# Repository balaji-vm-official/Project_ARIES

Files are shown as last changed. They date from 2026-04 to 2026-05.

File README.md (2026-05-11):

# Project ARIES: Automatic Robotic Interchangeable End Effector System

  **Project ARIES** is a smart, universal connector system designed to transform single-purpose robotic arms into versatile, multi-purpose industrial tools. By automating the end-effector switching process, ARIES eliminates manual intervention and reduces operational downtime.

  The system features a unique **Passive Docking Mechanism**: it requires no electricity to dock/undock, yet includes a dedicated power passthrough section to provide electricity to the end-effectors once connected.

---

## 🛠 System Overview

The system consists of three primary layers:

1. **Host:** The robotic arm.
2. **Connector:** The bridge between the host and tool, featuring three distinct sections:
    * **Top:** A specialized cut section for host engagement.
    * **Body:** Dual spring-activated mechanisms for secure locking and load-bearing.
    * **Bottom:** The interface where the specific end-effector is mounted.

3. **End-Effectors:** Currently supports a Mechanical Gripper and a Magnetic Gripper.

### Control Stack

The robotic arm is controlled via **ROS2 Jazzy** and **MoveIt2** for path planning, with hardware execution handled by an **Arduino UNO R3**.

> [!NOTE]
> For deep-dive technical details, please view the explanation files in each directory:
> [3D CAD Models](https://github.com/balaji-vm-official/Project_ARIES/blob/main/3D_CAD_Models/3D_CAD_Models.Explanation.md) | [Circuit Diagram](https://github.com/balaji-vm-official/Project_ARIES/blob/main/Circuit_Diagram/Circuit_Diagram.Explanation.md) | [ROS Workspace](https://github.com/balaji-vm-official/Project_ARIES/blob/main/ros-ws/ros-ws.Explanation.md)

---

## 📄 Publication & Citation

This project has been peer-reviewed and published in the *EPJ Web of Conferences*.

* **Title:** Automatic Robotic Interchangeable End Effector System (ARIES)
* **Authors:** Balaji V. M., Ponnarasan S. A., Srinivasan K., K. K. Manivannan, K. Gobivel
* **Journal:** *EPJ Web of Conferences*, Vol. 363, 01005 (2026)
* **Link:** [Read the full paper here](https://www.epj-conferences.org/10.1051/epjconf/202636301005)

### Citation (BibTeX)

If you use this work or codebase in your research, please use the following citation:

```bibtex
@article{aries2026,
  author = {Balaji, V. M. and Ponnarasan, S. A. and Srinivasan, K. and Manivannan, K. K. and Gobivel, K.},
  title = {Automatic Robotic Interchangeable End Effector System (ARIES)},
  journal = {EPJ Web of Conferences},
  volume = {363},
  pages = {01005},
  year = {2026},
  doi = {10.1051/epjconf/202636301005}
}

```

---

## 📸 Media Gallery

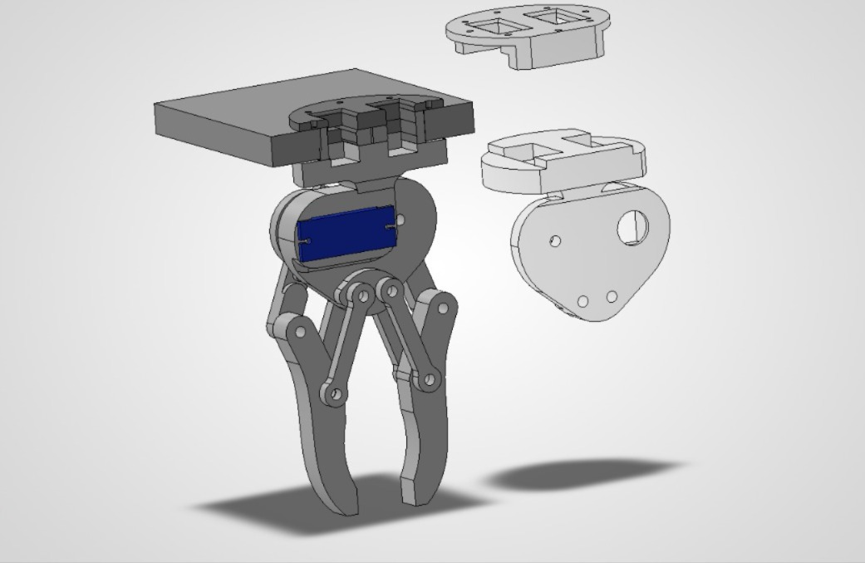
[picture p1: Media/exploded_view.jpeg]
Exploded view


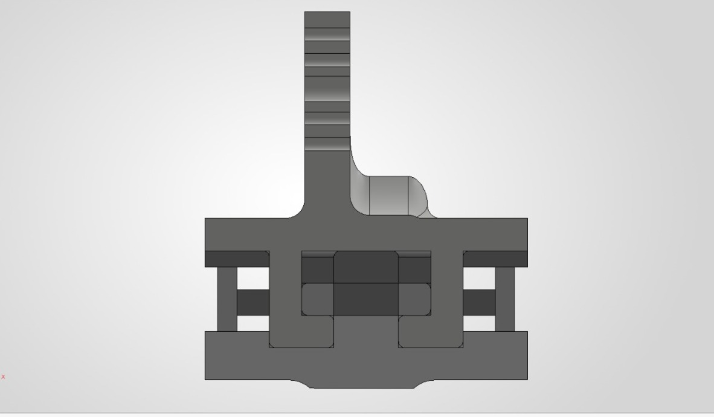
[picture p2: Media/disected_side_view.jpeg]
Disected view


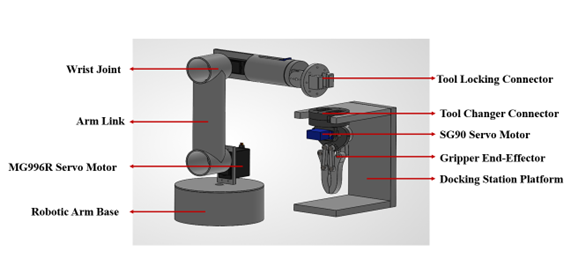
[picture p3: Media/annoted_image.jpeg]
Annoted image


---

## 🚀 Setup & Installation

### Software Requirements

* **ROS2 Jazzy:** [Installation Guide](https://docs.ros.org/en/jazzy/Installation/Ubuntu-Install-Debs.html)
* **MoveIt2:** [Binary Installation](https://moveit.ai/install-moveit2/binary/)
* **Arduino IDE:** [Download](https://www.arduino.cc/en/software/)
* **KiCAD:** [PCB Design Suite](https://www.kicad.org/download/)
* **SW to URDF Exporter:** [Wiki Link](https://wiki.ros.org/sw_urdf_exporter)

### Documentation & Resources

* **Official ROS Documentation:** [ROS Wiki](https://wiki.ros.org/)
* **MoveIt2 Tutorials:** [Setup Assistant Guide](https://moveit.picknik.ai/main/doc/examples/setup_assistant/setup_assistant_tutorial.html)
* **CAD Models:** [GrabCAD Library](https://grabcad.com/library)

---

## 👥 Contributors

* **Balaji V. M.** ([@balaji-vm-official](https://www.google.com/search?q=https://github.com/balaji-vm-official))
* **Ponnarasan S. A.**
* **Srinivasan K.**
* **Supervisor:** Mr. K.K. Manivannan (Assistant Professor, Mechatronics Engineering)

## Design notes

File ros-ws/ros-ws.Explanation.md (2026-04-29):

First install ROS2 and MoveIt2 from the given link before starting.<br/>  <br/> 

To avoid sourcing ros2 and it's required components everytime in the terminal individually and also not wanting to to also upload in the "~/.bashrc" file. 
I used the "ros2.sh" file to source everytime when it needed.

But before using the "ros2.sh" file make sure to change the location of the ros-ws folder as per the location that you saved. 
This file is movable so, if you move this file to home you can source it directly without any hassle. 

The robotic arm's model is given as "roboassem.urdf" and the gripper's models (that also includes both connector and the end effector) is given as "holdassem.urdf".

To simulate both model at same time, i used full.xacro to combine both the robotic arm (roboassem.urdf.xacro) and gripper (holdassem.urdf.xacro).
So to run each urdf file, i made seperate launch.py file to simulate in Rviz2. One launch.py file and one controller.yaml for each urdf.xacro file.<br/>  <br/> 

To make the already existing file compatable with MoveIt2, put the following command in terminal after sourcing to get a setup file make this process simple.
    
    "ros2 launch moveit_setup_assistant setup_assistant.launch.py" 

To launch the Moveit2 file run the following command in terminal after sourcing.
    
    "ros2 launch panda_moveit_config demo.launch.py" 

To connect MoveIt2 and Arduino UNO R3, <br/>  <br/> 

- First upload "ard_connect.ino" in the ard-connect folder (ros-ws/src/aries/ard_connect).
- Next run "ros2_to_arduino_bridge.py" in seperate terminal after the demo.launch.py is launched.
- Finally run "run_sequence.py" in seperate terminal if you want to want to run the robotic arm in pre planned sequence. This also work even when Arduino is not connected.<br/>  <br/> 

To learn more, visit the official documentations to get clear in-depth knowledge.

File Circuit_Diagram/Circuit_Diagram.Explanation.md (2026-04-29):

This circuit is made using KiCAD a free open source software. This is a accurate depiction of the circuit connected to the robotic arm for ROS2 control. 

Each servo motor is connected directly to a PWM suppported pin the Arduino UNO R3 that is given by,

   - 03 - rotate1 
   - 05 - link1
   - 06 - link2
   - 09 - rotate2
   - 10 - end
   - 11 - gripper

The Arduino UNO and all servo motors are directly powered by a 5V adapter so that the motors can gets uninterrupted power supply.

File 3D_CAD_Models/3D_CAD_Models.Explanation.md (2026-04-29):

This project is totally made in SolidWorks and some generic parts like motors are taken from GrabCAD. 

- holdassem folder consist of all the parts related to the connector.

- roboassem folder consist of all the parts related to the robotic arm.

- SolidWorks to URDF folder consist of urdf files that are directly converted from the assembly file using "SolidWorks to URDF Exporter" tool. 

- This URDF can work on both ROS1 and ROS2 but the launch files directly works on ROS1 and not on ROS2. ROS2 needs its own launch.py file to show in Rviz2.

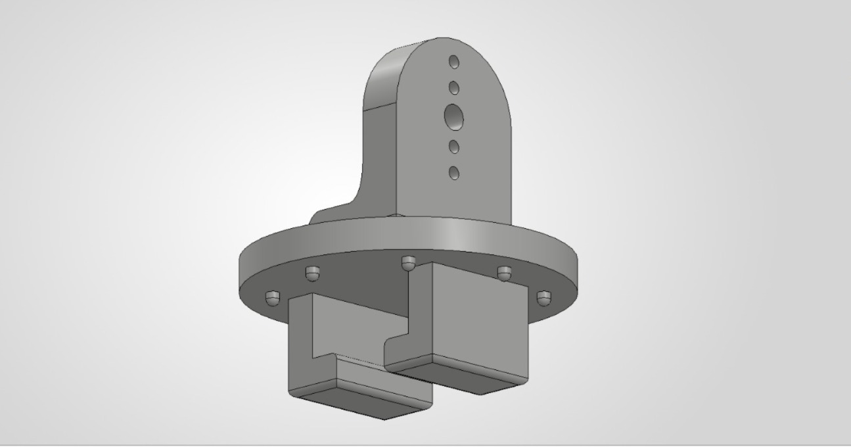
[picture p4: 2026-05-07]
Media/arm_end.jpeg

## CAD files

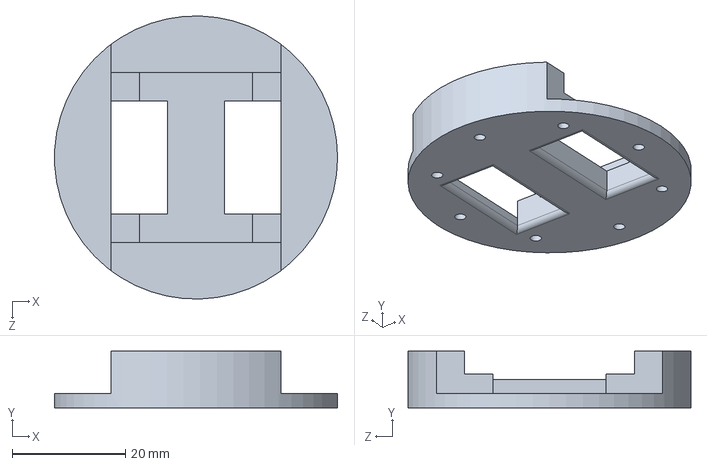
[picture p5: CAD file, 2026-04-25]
3D_CAD_Models/holdassem/connector/top.SLDPRT
50.0 x 10.0 x 50.0 mm

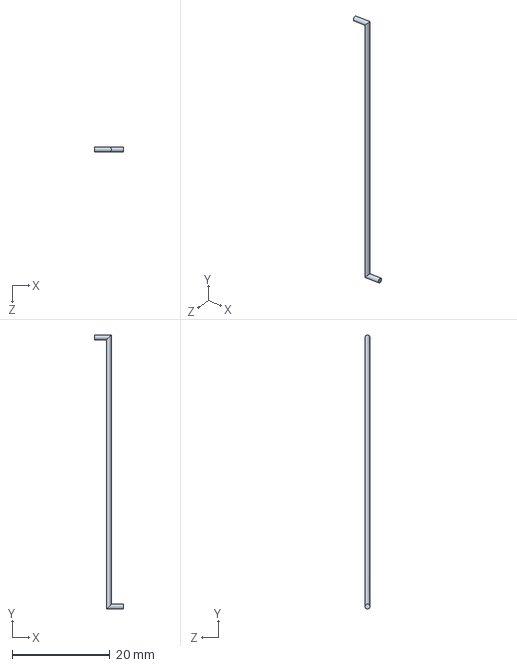
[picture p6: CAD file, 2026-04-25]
3D_CAD_Models/holdassem/mag_gripper/mlink.SLDPRT
6.00 x 56.0 x 1.00 mm

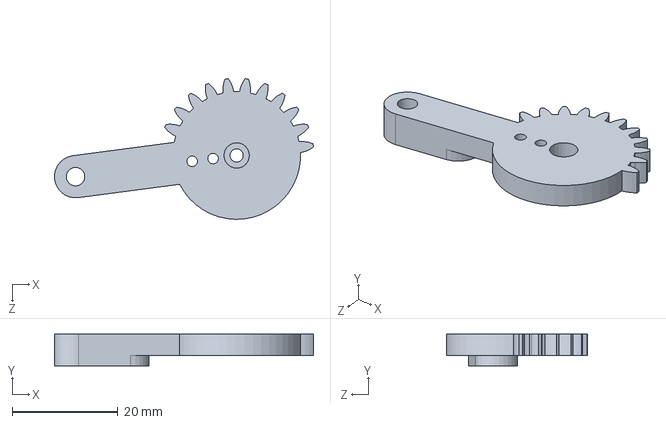
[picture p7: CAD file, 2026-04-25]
3D_CAD_Models/holdassem/mech_gripper/sgear.SLDPRT
49.0 x 6.00 x 26.6 mm

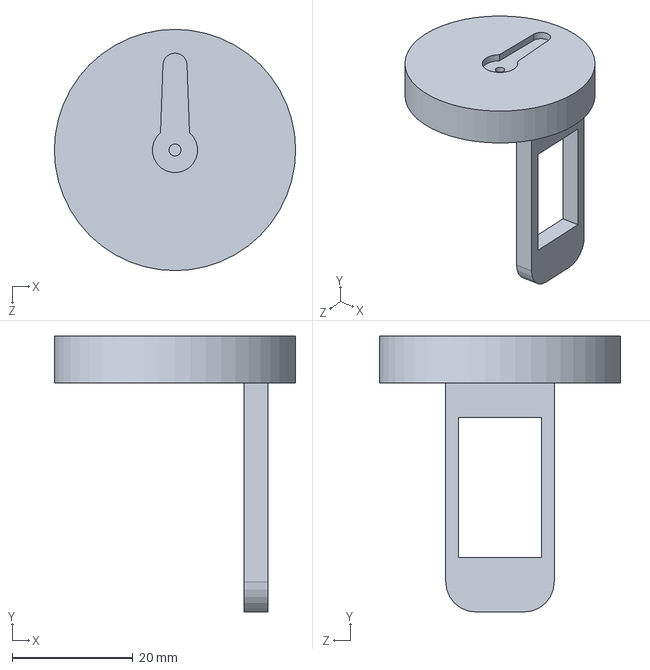
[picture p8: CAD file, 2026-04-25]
3D_CAD_Models/roboassem/rotate2.SLDPRT
40.0 x 45.8 x 40.0 mm

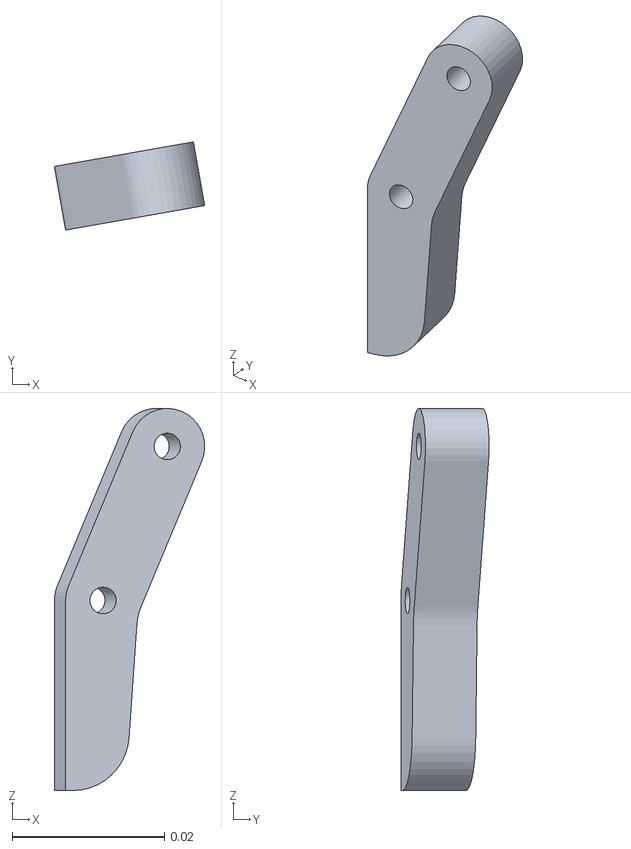
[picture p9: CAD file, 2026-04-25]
3D_CAD_Models/SolidWorks to URDF/holdassem/meshes/sfinger.STL
0.0198 x 0.0116 x 0.0503

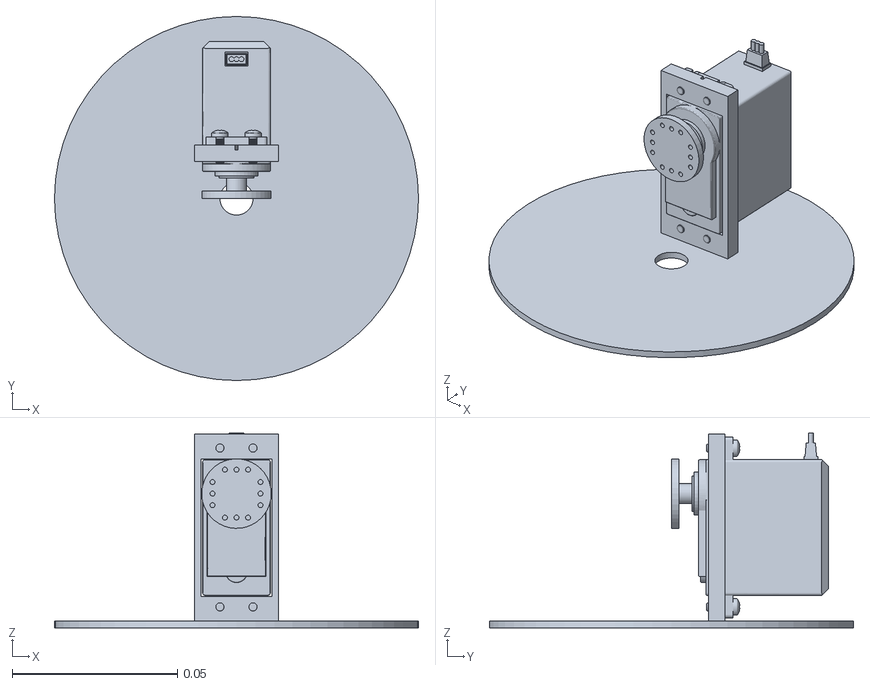
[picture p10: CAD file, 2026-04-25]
3D_CAD_Models/SolidWorks to URDF/roboassem/meshes/rotate1.STL
0.11 x 0.11 x 0.0588

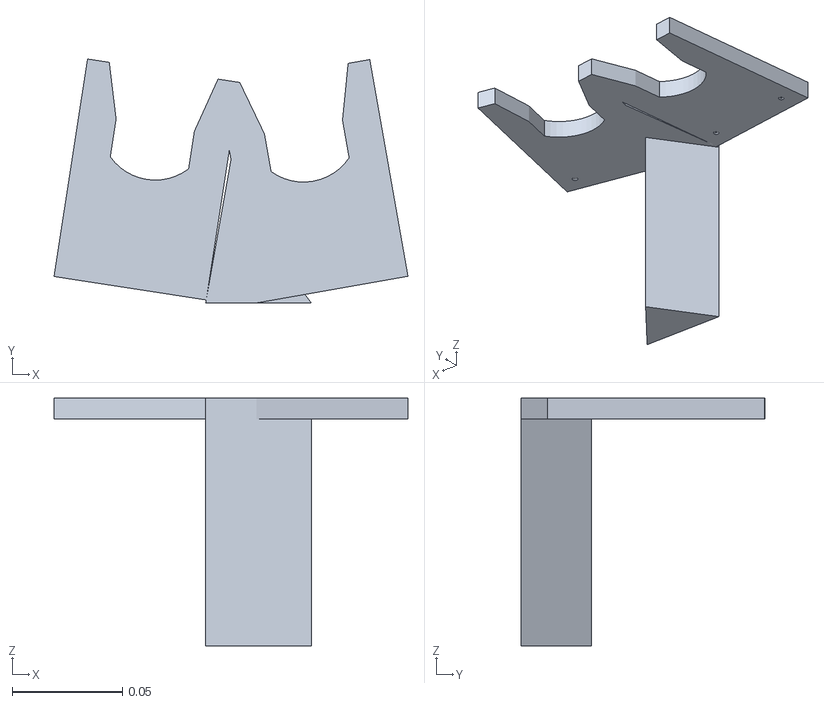
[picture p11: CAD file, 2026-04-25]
ros-ws/src/aries/meshes/holdassem/hbase.STL
0.161 x 0.111 x 0.112

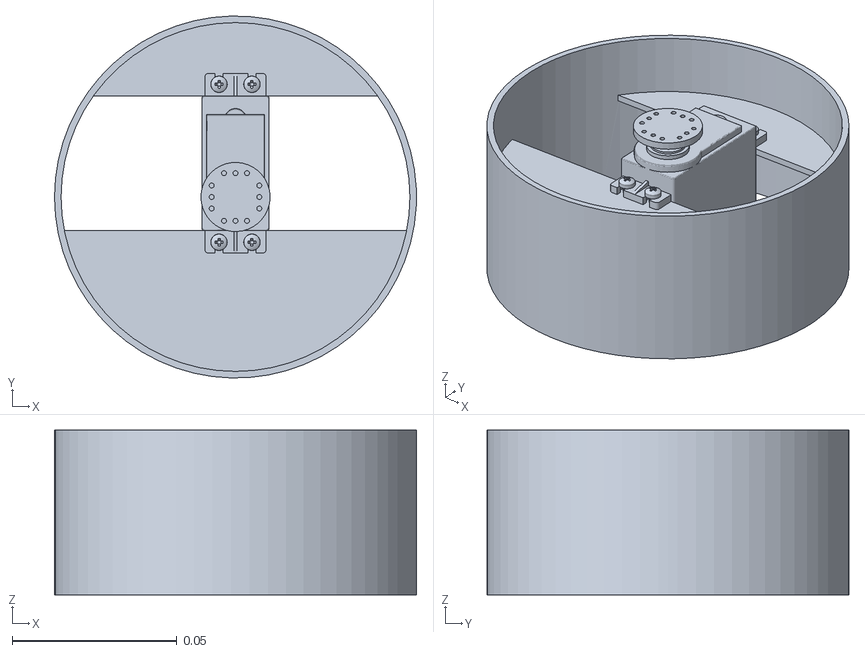
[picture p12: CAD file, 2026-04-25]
ros-ws/src/aries/meshes/roboassem/base.STL
0.11 x 0.11 x 0.05

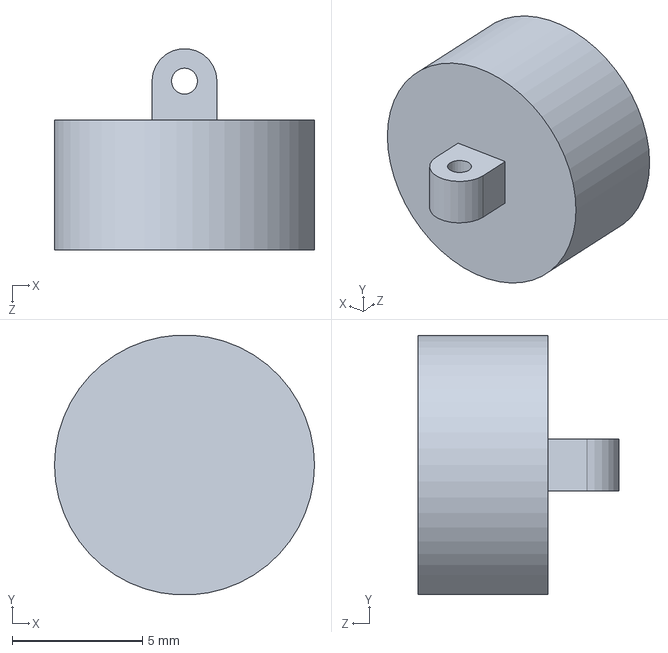
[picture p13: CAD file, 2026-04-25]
3D_CAD_Models/holdassem/mag_gripper/magnet.SLDPRT
10.0 x 9.98 x 7.74 mm

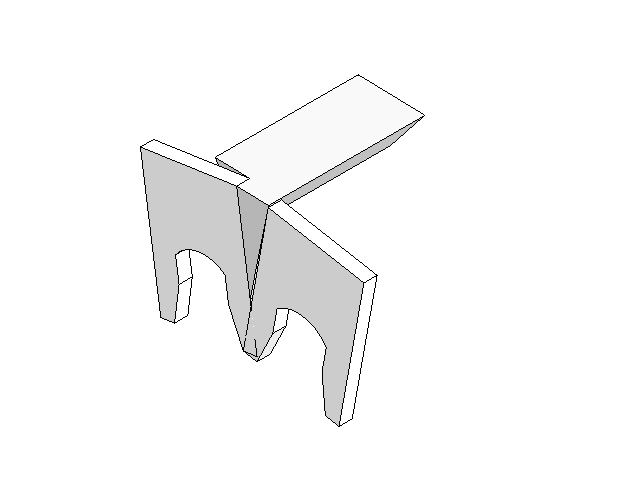
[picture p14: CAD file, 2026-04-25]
3D_CAD_Models/holdassem/hbase.SLDASM
stand
holder x 2

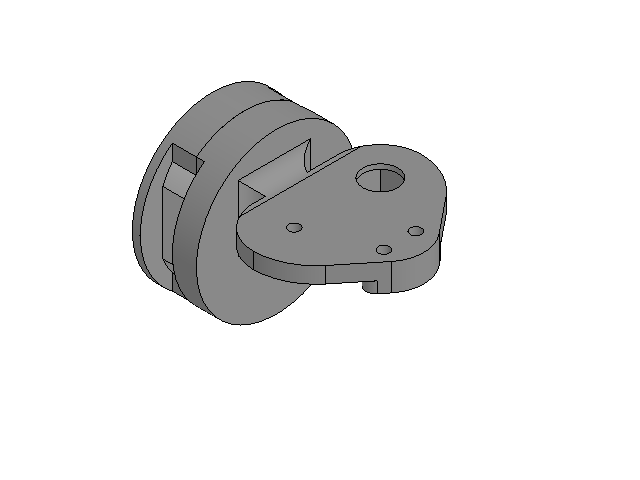
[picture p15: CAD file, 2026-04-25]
3D_CAD_Models/holdassem/connector/connector assem.SLDASM
bottom
button x 2
top

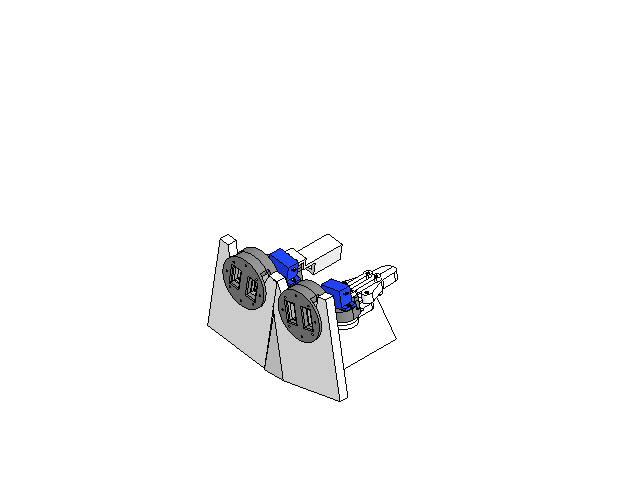
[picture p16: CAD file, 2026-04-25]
3D_CAD_Models/holdassem/holdassem.SLDASM
stand
holder x 2
bottom x 2
button x 4
top x 2
Servo Micro x 2
Microservo horn x 2
mag holder
magnet
mlink
cr pan head screw_is x 16
sgear
gear
link x 4
finger x 2

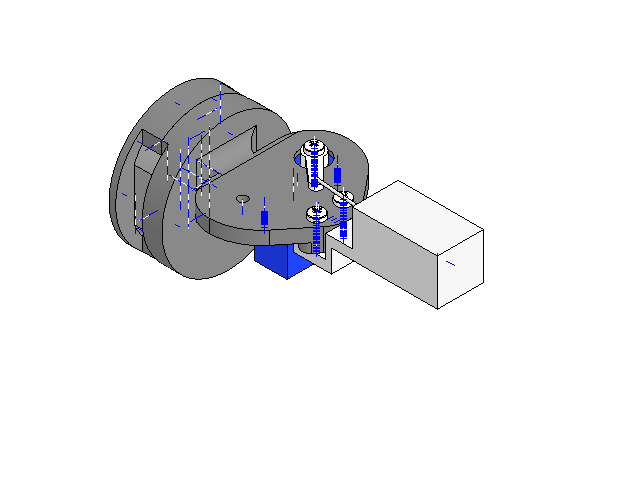
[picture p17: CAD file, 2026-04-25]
3D_CAD_Models/holdassem/mag_gripper/mag gripper assem.SLDASM
bottom
button x 2
top
Servo Micro
Microservo horn
mag holder
magnet
mlink
cr pan head screw_is x 5

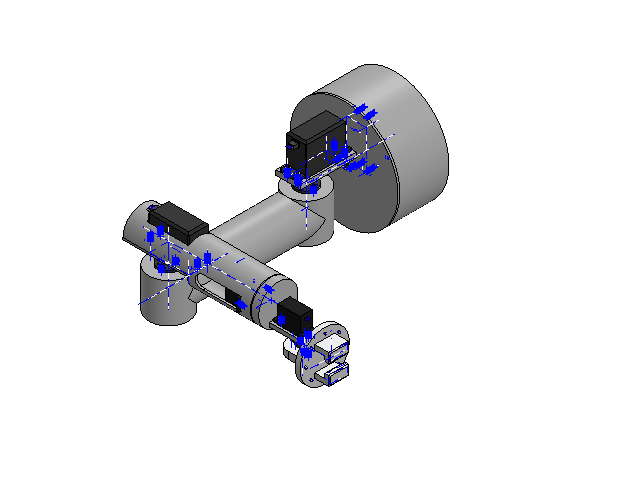
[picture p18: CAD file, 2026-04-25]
3D_CAD_Models/roboassem/roboassem.SLDASM
rotate1
base
motorb x 3
link1
link2
motors x 2
rotate2
motors_horn x 2
Component1.step
cr pan head screw_is x 25

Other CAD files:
3D_CAD_Models/holdassem/mech_gripper/mech gripper Assem trial.SLDASM
3D_CAD_Models/holdassem/mech_gripper/mech gripper Assem.SLDASM
ros-ws/install/aries/share/aries/meshes/holdassem/finger.STL
ros-ws/install/aries/share/aries/meshes/roboassem/link1.STL
3D_CAD_Models/SolidWorks to URDF/holdassem/meshes/button1.STL
3D_CAD_Models/SolidWorks to URDF/holdassem/meshes/button2.STL
3D_CAD_Models/SolidWorks to URDF/holdassem/meshes/connector.STL
3D_CAD_Models/SolidWorks to URDF/holdassem/meshes/finger.STL
3D_CAD_Models/SolidWorks to URDF/holdassem/meshes/gear.STL
3D_CAD_Models/SolidWorks to URDF/holdassem/meshes/horn.STL
3D_CAD_Models/SolidWorks to URDF/holdassem/meshes/link.STL
3D_CAD_Models/SolidWorks to URDF/holdassem/meshes/magnet.STL
3D_CAD_Models/SolidWorks to URDF/holdassem/meshes/mbutton1.STL
3D_CAD_Models/SolidWorks to URDF/holdassem/meshes/mbutton2.STL
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

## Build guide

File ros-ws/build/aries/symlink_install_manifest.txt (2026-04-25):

/home/comrade/Documents/Project_ARIES/ros-ws/install/aries/share/aries/ard_connect/ard_connect.ino
/home/comrade/Documents/Project_ARIES/ros-ws/install/aries/share/aries/ard_connect/ros2_to_arduino_bridge.py
/home/comrade/Documents/Project_ARIES/ros-ws/install/aries/share/aries/ard_connect/run_sequence.py
/home/comrade/Documents/Project_ARIES/ros-ws/install/aries/share/aries/config/ardcontroller.yaml
/home/comrade/Documents/Project_ARIES/ros-ws/install/aries/share/aries/config/fullcontroller.yaml
/home/comrade/Documents/Project_ARIES/ros-ws/install/aries/share/aries/config/holdcontroller.yaml
/home/comrade/Documents/Project_ARIES/ros-ws/install/aries/share/aries/config/robocontroller.yaml
/home/comrade/Documents/Project_ARIES/ros-ws/install/aries/share/aries/launch/full_rviz.launch.py
/home/comrade/Documents/Project_ARIES/ros-ws/install/aries/share/aries/launch/holdassem_rviz.launch.py
/home/comrade/Documents/Project_ARIES/ros-ws/install/aries/share/aries/launch/roboassem_rviz.launch.py
/home/comrade/Documents/Project_ARIES/ros-ws/install/aries/share/aries/meshes/holdassem/button1.STL
/home/comrade/Documents/Project_ARIES/ros-ws/install/aries/share/aries/meshes/holdassem/button2.STL
/home/comrade/Documents/Project_ARIES/ros-ws/install/aries/share/aries/meshes/holdassem/connector.STL
/home/comrade/Documents/Project_ARIES/ros-ws/install/aries/share/aries/meshes/holdassem/finger.STL
/home/comrade/Documents/Project_ARIES/ros-ws/install/aries/share/aries/meshes/holdassem/gear.STL
/home/comrade/Documents/Project_ARIES/ros-ws/install/aries/share/aries/meshes/holdassem/hbase.STL
/home/comrade/Documents/Project_ARIES/ros-ws/install/aries/share/aries/meshes/holdassem/horn.STL
/home/comrade/Documents/Project_ARIES/ros-ws/install/aries/share/aries/meshes/holdassem/link.STL
/home/comrade/Documents/Project_ARIES/ros-ws/install/aries/share/aries/meshes/holdassem/magnet.STL
/home/comrade/Documents/Project_ARIES/ros-ws/install/aries/share/aries/meshes/holdassem/mbutton1.STL
/home/comrade/Documents/Project_ARIES/ros-ws/install/aries/share/aries/meshes/holdassem/mbutton2.STL
/home/comrade/Documents/Project_ARIES/ros-ws/install/aries/share/aries/meshes/holdassem/mconnector.STL
/home/comrade/Documents/Project_ARIES/ros-ws/install/aries/share/aries/meshes/holdassem/rod.STL
/home/comrade/Documents/Project_ARIES/ros-ws/install/aries/share/aries/meshes/holdassem/sfinger.STL
/home/comrade/Documents/Project_ARIES/ros-ws/install/aries/share/aries/meshes/holdassem/sgear.STL
/home/comrade/Documents/Project_ARIES/ros-ws/install/aries/share/aries/meshes/holdassem/slink.STL
/home/comrade/Documents/Project_ARIES/ros-ws/install/aries/share/aries/meshes/roboassem/base.STL
/home/comrade/Documents/Project_ARIES/ros-ws/install/aries/share/aries/meshes/roboassem/end.STL
/home/comrade/Documents/Project_ARIES/ros-ws/install/aries/share/aries/meshes/roboassem/link1.STL
/home/comrade/Documents/Project_ARIES/ros-ws/install/aries/share/aries/meshes/roboassem/link2.STL
/home/comrade/Documents/Project_ARIES/ros-ws/install/aries/share/aries/meshes/roboassem/rotate1.STL
/home/comrade/Documents/Project_ARIES/ros-ws/install/aries/share/aries/meshes/roboassem/rotate2.STL
/home/comrade/Documents/Project_ARIES/ros-ws/install/aries/share/aries/urdf/full.xacro
/home/comrade/Documents/Project_ARIES/ros-ws/install/aries/share/aries/urdf/holdassem.csv
/home/comrade/Documents/Project_ARIES/ros-ws/install/aries/share/aries/urdf/holdassem.urdf
/home/comrade/Documents/Project_ARIES/ros-ws/install/aries/share/aries/urdf/roboassem.csv
/home/comrade/Documents/Project_ARIES/ros-ws/install/aries/share/aries/urdf/roboassem.urdf
/home/comrade/Documents/Project_ARIES/ros-ws/install/aries/share/aries/worlds/holdassem.rviz
/home/comrade/Documents/Project_ARIES/ros-ws/install/aries/share/aries/worlds/roboassem.rviz
/home/comrade/Documents/Project_ARIES/ros-ws/install/aries/lib/aries/ros2_to_arduino_bridge.py
/home/comrade/Documents/Project_ARIES/ros-ws/install/aries/share/ament_index/resource_index/package_run_dependencies/aries
/home/comrade/Documents/Project_ARIES/ros-ws/install/aries/share/ament_index/resource_index/parent_prefix_path/aries
/home/comrade/Documents/Project_ARIES/ros-ws/install/aries/share/aries/environment/ament_prefix_path.sh
/home/comrade/Documents/Project_ARIES/ros-ws/install/aries/share/aries/environment/ament_prefix_path.dsv
/home/comrade/Documents/Project_ARIES/ros-ws/install/aries/share/aries/environment/path.sh
/home/comrade/Documents/Project_ARIES/ros-ws/install/aries/share/aries/environment/path.dsv
/home/comrade/Documents/Project_ARIES/ros-ws/install/aries/share/aries/local_setup.bash
/home/comrade/Documents/Project_ARIES/ros-ws/install/aries/share/aries/local_setup.sh
/home/comrade/Documents/Project_ARIES/ros-ws/install/aries/share/aries/local_setup.zsh
/home/comrade/Documents/Project_ARIES/ros-ws/install/aries/share/aries/local_setup.dsv
/home/comrade/Documents/Project_ARIES/ros-ws/install/aries/share/aries/package.dsv
/home/comrade/Documents/Project_ARIES/ros-ws/install/aries/share/ament_index/resource_index/packages/aries
/home/comrade/Documents/Project_ARIES/ros-ws/install/aries/share/aries/cmake/ariesConfig.cmake
/home/comrade/Documents/Project_ARIES/ros-ws/install/aries/share/aries/cmake/ariesConfig-version.cmake
/home/comrade/Documents/Project_ARIES/ros-ws/install/aries/share/aries/package.xml

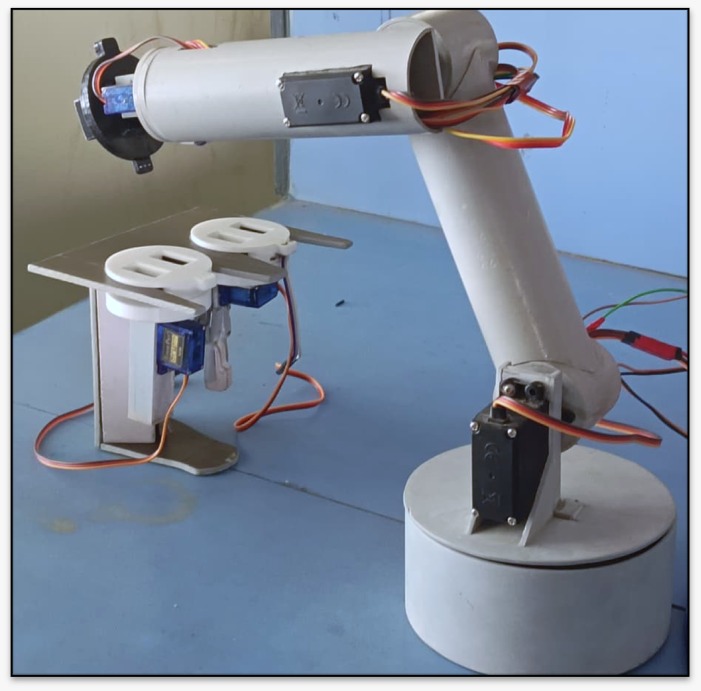
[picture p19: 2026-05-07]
Media/full_setup.jpeg

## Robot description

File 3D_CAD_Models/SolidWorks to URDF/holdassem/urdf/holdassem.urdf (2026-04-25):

<?xml version="1.0" encoding="utf-8"?>
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
<robot name="holdassem">
  <link name="hbase">
    <inertial>
      <origin xyz="-0.0080385 0.021105 0.086708" rpy="0 0 0" />
      <mass value="0.21146" />
      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
    </inertial>
    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
  </link>
  <link name="connector">
    <inertial>
      <origin xyz="0.00275 -0.00097993 -0.022656" rpy="0 0 0" />
      <mass value="0.044045" />
      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
    </inertial>
    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
  </link>
  <joint name="jconnector" type="prismatic">
    <origin xyz="0.020445 0.069272 0.115" rpy="0 0 0" />
    <parent link="hbase" />
    <child link="connector" />
    <axis xyz="0.17365 -0.98481 0" />
    <limit lower="0" upper="0.04" effort="0" velocity="0" />
  </joint>
  <link name="sgear">
    <inertial>
      <origin xyz="-0.00090699 0.0018177 -0.0067816" rpy="0 0 0" />
      <mass value="0.0055987" />
      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
    </inertial>
    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
  </link>
  <joint name="jsgear" type="revolute">
    <origin xyz="0.018779 -0.014646 -0.0365" rpy="0 0 0" />
    <parent link="connector" />
    <child link="sgear" />
    <axis xyz="0.17365 -0.98481 0" />
    <limit lower="-0.8" upper="0" effort="0" velocity="0" />
  </joint>
  <link name="sfinger">
    <inertial>
      <origin xyz="-0.0061362 -0.001082 -0.019217" rpy="0 0 0" />
      <mass value="0.0049563" />
      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
    </inertial>
    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
  </link>
  <joint name="jsfinger" type="revolute">
    <origin xyz="-0.0026832 0.0094781 -0.030734" rpy="0 0 0" />
    <parent link="sgear" />
    <child link="sfinger" />
    <axis xyz="0.17365 -0.98481 0" />
    <limit lower="0" upper="0.8" effort="0" velocity="0" />
    <mimic joint="jsgear" multiplier="-1" offset="0" />
  </joint>
  <link name="slink">
    <inertial>
      <origin xyz="-0.0014048 0.0058969 -0.016516" rpy="0 0 0" />
      <mass value="0.002206" />
      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
    </inertial>
    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
  </link>
  <joint name="jslink" type="revolute">
    <origin xyz="0.0093974 -0.012696 -0.0565" rpy="0 0 0" />
    <parent link="connector" />
    <child link="slink" />
    <axis xyz="0.17365 -0.98481 0" />
    <limit lower="-0.8" upper="0" effort="0" velocity="0" />
    <mimic joint="jsgear" multiplier="1" offset="0" />
  </joint>
  <link name="gear">
    <inertial>
      <origin xyz="0.0003177 0.00011857 -0.0062925" rpy="0 0 0" />
      <mass value="0.0052567" />
      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
    </inertial>
    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
  </link>
  <joint name="gear" type="revolute">
    <origin xyz="-0.0081555 -0.016806 -0.0365" rpy="0 0 0" />
    <parent link="connector" />
    <child link="gear" />
    <axis xyz="-0.17365 0.98481 0" />
    <limit lower="-0.8" upper="0" effort="0" velocity="0" />
    <mimic joint="jsgear" multiplier="1" offset="0" />
  </joint>
  <link name="finger">
    <inertial>
      <origin xyz="0.0061173 0.0010787 -0.019223" rpy="0 0 0" />
      <mass value="0.0049563" />
      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
    </inertial>
    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
  </link>
  <joint name="jfinger" type="revolute">
    <origin xyz="-0.0024724 0.0069259 -0.030725" rpy="0 0 0" />
    <parent link="gear" />
    <child link="finger" />
    <axis xyz="-0.17365 0.98481 0" />
    <limit lower="0" upper="0.8" effort="0" velocity="0" />
    <mimic joint="gear" multiplier="-1" offset="0" />
  </joint>
  <link name="link">
    <inertial>
      <origin xyz="-0.0014048 0.0058969 -0.016516" rpy="0 0 0" />
      <mass value="0.002206" />
      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
    </inertial>
    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
  </link>
  <joint name="jlink" type="revolute">
    <origin xyz="-0.00045071 -0.014432 -0.0565" rpy="0 0 0" />
    <parent link="connector" />
    <child link="link" />
    <axis xyz="0.17365 -0.98481 0" />
    <limit lower="0" upper="0.8" effort="0" velocity="0" />
    <mimic joint="gear" multiplier="-1" offset="0" />
  </joint>
  <link name="button1">
    <inertial>
      <origin xyz="-0.78409 -0.83398 -1.2914" rpy="0 0 0" />
      <mass value="0.0018987" />
      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
    </inertial>
    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
  </link>
  <joint name="jbutton1" type="prismatic">
    <origin xyz="0.79372 0.83568 1.284" rpy="0 0 0" />
    <parent link="connector" />
    <child link="button1" />
    <axis xyz="0.98481 0.17365 0" />
    <limit lower="-0.004" upper="0" effort="0" velocity="0" />
  </joint>
  <link name="button2">
    <inertial>
      <origin xyz="-0.81402 -0.83738 -1.2914" rpy="0 0 0" />
      <mass value="0.0018987" />
      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
    </inertial>
    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
  </link>
  <joint name="jbutton2" type="prismatic">
    <origin xyz="0.80439 0.83568 1.284" rpy="0 0 0" />
    <parent link="connector" />
    <child link="button2" />
    <axis xyz="0.98481 0.17365 0" />
    <limit lower="0" upper="0.004" effort="0" velocity="0" />
    <mimic joint="jbutton1" multiplier="-1" offset="0" />
  </joint>
  <link name="mconnector">
    <inertial>
      <origin xyz="0 0 0" rpy="0 0 0" />
      <mass value="0" />
      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
    </inertial>
    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
  </link>
  <joint name="jmconnector" type="prismatic">
    <origin xyz="-0.046918 0.070176 0.115" rpy="0 0 0" />
    <parent link="hbase" />
    <child link="mconnector" />
    <axis xyz="-0.15239 -0.98832 0" />
    <limit lower="0" upper="0.04" effort="0" velocity="0" />
  </joint>
  <link name="horn">
    <inertial>
      <origin xyz="-0.0024811 0.001454 -0.0028938" rpy="0 0 0" />
      <mass value="0.0017572" />
      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
    </inertial>
    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
  </link>
  <joint name="jhorn" type="revolute">
    <origin xyz="0.013671 -0.016005 -0.0365" rpy="0 0 0" />
    <parent link="mconnector" />
    <child link="horn" />
    <axis xyz="0.15239 0.98832 0" />
    <limit lower="-0.8" upper="0" effort="0" velocity="0" />
  </joint>
  <link name="rod">
    <inertial>
      <origin xyz="-0.002235 -0.0011521 -0.027471" rpy="0 0 0" />
      <mass value="4.7921E-05" />
      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
    </inertial>
    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
  </link>
  <joint name="jrod" type="revolute">
    <origin xyz="-0.0097633 0.0012314 -0.010608" rpy="0 0 0" />
    <parent link="horn" />
    <child link="rod" />
    <axis xyz="0.15239 0.98832 0" />
    <limit lower="0" upper="0.88" effort="0" velocity="0" />
    <mimic joint="jhorn" multiplier="-1.1" offset="0" />
  </joint>
  <link name="magnet">
    <inertial>
      <origin xyz="-2.299E-05 -0.00016933 -0.0038585" rpy="0 0 0" />
      <mass value="0.00040354" />
      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
    </inertial>
    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
  </link>
  <joint name="jmagnet" type="continuous">
    <origin xyz="-0.0044694 -0.0023041 -0.054933" rpy="0 0 0" />
    <parent link="rod" />
    <child link="magnet" />
    <axis xyz="0.15239 0.98832 0" />
    <limit lower="-0.8" upper="0" effort="0" velocity="0" />
    <mimic joint="jhorn" multiplier="0.1" offset="0" />
  </joint>
  <link name="mbutton1">
    <inertial>
      <origin xyz="0.0047248 -0.00072852 0.00013509" rpy="0 0 0" />
      <mass value="0.0018987" />
      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
    </inertial>
    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
  </link>
  <joint name="jmbutton1" type="prismatic">
    <origin xyz="0.0049416 -0.00076195 -0.0075" rpy="0 0 0" />
    <parent link="mconnector" />
    <child link="mbutton1" />
    <axis xyz="0.98832 -0.15239 0" />
    <limit lower="-0.004" upper="0" effort="0" velocity="0" />
  </joint>
  <link name="mbutton2">
    <inertial>
      <origin xyz="-0.0047248 0.00072852 0.00013509" rpy="0 0 0" />
      <mass value="0.0018987" />
      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
    </inertial>
    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
  </link>
  <joint name="jmbutton2" type="prismatic">
    <origin xyz="-0.0049416 0.00076195 -0.0075" rpy="0 0 0" />
    <parent link="mconnector" />
    <child link="mbutton2" />
    <axis xyz="0.98832 -0.15239 0" />
    <limit lower="0" upper="0.004" effort="0" velocity="0" />
    <mimic joint="jmbutton1" multiplier="-1" offset="0" />
  </joint>
</robot>

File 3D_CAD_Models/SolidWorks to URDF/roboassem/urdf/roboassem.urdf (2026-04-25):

<?xml version="1.0" encoding="utf-8"?>
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
<robot name="roboassem">
  <link name="base">
    <inertial>
      <origin xyz="-5.6544E-10 0.0032663 0.024781" rpy="0 0 0" />
      <mass value="0.077397" />
      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
    </inertial>
    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
  </link>
  <link name="rotate1">
    <inertial>
      <origin xyz="7.8652E-10 0.017196 0.01967" rpy="0 0 0" />
      <mass value="0.055642" />
      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
    </inertial>
    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
  </link>
  <joint name="jrotate1" type="revolute">
    <origin xyz="0 0 0.051" rpy="0 0 0" />
    <parent link="base" />
    <child link="rotate1" />
    <axis xyz="0 0 1" />
    <limit lower="-1.57" upper="1.57" effort="0" velocity="0" />
    <safety_controller soft_upper_limit="1.5" soft_lower_limit="-1.5" k_velocity="0" />
  </joint>
  <link name="link1">
    <inertial>
      <origin xyz="3.0531E-07 0.0024668 0.070335" rpy="0 0 0" />
      <mass value="0.0493" />
      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
    </inertial>
    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
  </link>
  <joint name="jlink1" type="revolute">
    <origin xyz="0 -0.021019 0.039215" rpy="0 0 0" />
    <parent link="rotate1" />
    <child link="link1" />
    <axis xyz="0 1 0" />
    <limit lower="-1.222" upper="1.92" effort="0" velocity="0" />
    <safety_controller soft_upper_limit="1.85" soft_lower_limit="-1.15" k_velocity="0" />
  </joint>
  <link name="link2">
    <inertial>
      <origin xyz="0.032867 0.020587 0.00045109" rpy="0 0 0" />
      <mass value="0.067771" />
      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
    </inertial>
    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
  </link>
  <joint name="jlink2" type="revolute">
    <origin xyz="0 0.025219 0.14033" rpy="0 0 0" />
    <parent link="link1" />
    <child link="link2" />
    <axis xyz="0 -1 0" />
    <limit lower="-1.222" upper="1.92" effort="0" velocity="0" />
    <safety_controller soft_upper_limit="1.85" soft_lower_limit="-1.15" k_velocity="0" />
  </joint>
  <link name="rotate2">
    <inertial>
      <origin xyz="0.011055 -0.0037097 2.4286E-05" rpy="0 0 0" />
      <mass value="0.016695" />
      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
    </inertial>
    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
  </link>
  <joint name="jrotate2" type="revolute">
    <origin xyz="0.10788 0.01655 0" rpy="0 0 0" />
    <parent link="link2" />
    <child link="rotate2" />
    <axis xyz="-1 0 0" />
    <limit lower="-1.57" upper="1.57" effort="0" velocity="0" />
    <safety_controller soft_upper_limit="1.5" soft_lower_limit="-1.5" k_velocity="0" />
  </joint>
  <link name="end">
    <inertial>
      <origin xyz="0.020161 0.0045965 8.9879E-09" rpy="0 0 0" />
      <mass value="0.021086" />
      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
    </inertial>
    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
  </link>
  <joint name="jend" type="revolute">
    <origin xyz="0.026025 -0.0278 0" rpy="0 0 0" />
    <parent link="rotate2" />
    <child link="end" />
    <axis xyz="0 -1 0" />
    <limit lower="-1.57" upper="1.57" effort="0" velocity="0" />
    <safety_controller soft_upper_limit="1.5" soft_lower_limit="-1.5" k_velocity="0" />
  </joint>
</robot>

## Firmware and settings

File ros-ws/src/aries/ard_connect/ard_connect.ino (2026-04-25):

/*
╔══════════════════════════════════════════════════════════════════════════════╗
║                         ros2_to_arduino.ino                                  ║
╠══════════════════════════════════════════════════════════════════════════════╣
║  WHAT THIS FILE DOES:                                                        ║
║    Runs ON the Arduino UNO. Receives servo angle commands from the laptop    ║
║    over USB, then smoothly moves each servo to its target angle.             ║
║                                                                              ║
║  PROTOCOL (how laptop and Arduino talk):                                     ║
║    Laptop → Arduino : "090,110,110,090,090,090\n"                            ║
║                        6 angles (0-180), comma-separated, newline at end     ║
║    Arduino → Laptop : same format echoed back as position feedback           ║
║    Arduino → Laptop : "READY\n" on startup                                   ║
║    Arduino → Laptop : "ERR:bad_count\n" if wrong number of values received   ║
║                                                                              ║
║  SERVO PIN ASSIGNMENTS:                                                      ║
║    Slot 0 → Pin  3  → jrotate1  (base rotation)        — MG996R              ║
║    Slot 1 → Pin  5  → jlink1    (arm segment 1)        — MG996R              ║
║    Slot 2 → Pin  6  → jlink2    (arm segment 2)        — MG996R              ║
║    Slot 3 → Pin  9  → jrotate2  (wrist rotation)       — MG90S               ║
║    Slot 4 → Pin 10  → jend      (wrist tilt)           — MG90S               ║
║    Slot 5 → Pin 11  → jsgear OR jhorn (end effector)   — SG90                ║
║                        Both share this pin — only one attached at a time     ║
║                                                                              ║
║  Valid PWM pins on Arduino UNO: 3, 5, 6, 9, 10, 11 (all used above)          ║
╚══════════════════════════════════════════════════════════════════════════════╝
*/

// ── INCLUDE SERVO LIBRARY ─────────────────────────────────────────────────────
// #include is like "import" in Python — loads extra tools into your sketch
// Servo.h is the built-in Arduino library that handles all PWM signal timing
#include <Servo.h>


// ══════════════════════════════════════════════════════════════════════════════
//  CONFIGURATION  ← edit these to change behaviour
// ══════════════════════════════════════════════════════════════════════════════

// How many servos. Must EXACTLY match NUM_JOINTS in ros2_to_arduino_bridge.py
#define NUM_JOINTS 6

// Smooth movement: how many degrees to move each update tick.
// Lower = smoother but takes longer.  Higher = faster but can be jerky.
// At STEP_SIZE=2 and UPDATE_MS=20 (50 Hz), max speed ≈ 100 degrees/second
#define STEP_SIZE  2

// How many milliseconds between each smooth-movement step.
// 20ms = 50 updates per second = 50 Hz
#define UPDATE_MS  20


// ══════════════════════════════════════════════════════════════════════════════
//  HARDWARE SETUP
// ══════════════════════════════════════════════════════════════════════════════

// Create 6 Servo objects — one remote-control per servo motor
Servo servos[NUM_JOINTS];

// Which Arduino pin each servo slot is wired to.
// The position in this array IS the slot number (array[0] = slot 0 = jrotate1)
// All 6 pins are PWM-capable (required for servo control)
//                    Slot :   0   1   2   3   4    5                               
int servo_pins[NUM_JOINTS] = { 3,  5,  6,  9,  10,  11 };

// Starting angle for each servo at power-on (degrees, 0-180)
// These match the zero_angle values in ros2_to_arduino_bridge.py's JOINT_MAP:
//   jrotate1=90, jlink1=110, jlink2=110, jrotate2=90, jend=90, j6=90
//                        Slot :    0   1    2    3   4   5                         
int default_angles[NUM_JOINTS] = {  90, 145, 110, 90, 90, 90 };


// ══════════════════════════════════════════════════════════════════════════════
//  RUNTIME STATE — these variables change as the program runs
// ══════════════════════════════════════════════════════════════════════════════

// Where each servo SHOULD end up (set by parse_command when ROS2 sends angles)
int target_angles[NUM_JOINTS];

// Where each servo IS right now (updated bit-by-bit each step toward target)
int current_angles[NUM_JOINTS];

// Text buffer to collect serial characters until we receive a complete line
char serial_buf[64];
int  buf_idx = 0;

// Timestamp of the last smooth-movement update (for timing with millis())
unsigned long last_update_time = 0;


// ══════════════════════════════════════════════════════════════════════════════
//  SETUP — runs ONCE when Arduino powers on or resets
// ══════════════════════════════════════════════════════════════════════════════

void setup() {
  // Start serial at 115200 baud. Must match baud_rate in ros2_to_arduino_bridge.py.
  // "Baud" = bits per second.  115200 baud ≈ 11,500 characters per second.
  Serial.begin(115200);

  // Initialize every servo to its starting angle
  for (int i = 0; i < NUM_JOINTS; i++) {
    // .attach() connects the Servo object to the physical PWM pin
    servos[i].attach(servo_pins[i]);

    // Set both current and target to the starting angle
    current_angles[i] = default_angles[i];
    target_angles[i]  = default_angles[i];

    // .write() sends a PWM pulse to actually move the servo to that angle
    servos[i].write(default_angles[i]);
  }

  // Short delay so all servos finish reaching their start positions
  // before we start accepting commands from ROS2
  delay(500);

  // Signal to the laptop that Arduino is ready.
  // ros2_to_arduino_bridge.py watches for this "READY" message before sending commands.
  Serial.println("READY");
}


// ══════════════════════════════════════════════════════════════════════════════
//  MAIN LOOP — runs REPEATEDLY forever, as fast as Arduino can manage
// ══════════════════════════════════════════════════════════════════════════════

void loop() {

  // ── READ INCOMING SERIAL DATA ─────────────────────────────────────────────
  // Serial.available() returns how many characters are waiting to be read.
  // We collect them one-by-one, building up a complete message in serial_buf,
  // until we see a newline ('\n') which marks the end of one command.
  while (Serial.available()) {
    char c = Serial.read();     // Read one character at a time

    if (c == '\n') {
      // End of message — process the complete line we built up
      serial_buf[buf_idx] = '\0';   // Null-terminate to make it a valid C string
      parse_command(serial_buf);    // Parse and apply the command
      buf_idx = 0;                  // Reset buffer for the next incoming message
    }
    else if (buf_idx < 63) {
      // Still receiving the current message — keep adding characters
      // The check buf_idx < 63 prevents buffer overflow (a safety guard)
      serial_buf[buf_idx++] = c;
    }
  }

  // ── SMOOTH SERVO MOVEMENT (rate-limited to UPDATE_MS) ─────────────────────
  // millis() returns the number of milliseconds since Arduino started.
  // We only advance the smooth movement every UPDATE_MS milliseconds.
  // This creates a steady heartbeat of tiny movements toward the target angle.
  unsigned long now = millis();
  if (now - last_update_time >= UPDATE_MS) {
    last_update_time = now;
    move_step();    // Each call moves every servo one STEP_SIZE closer to target
  }
}


// ══════════════════════════════════════════════════════════════════════════════
//  FUNCTION: parse_command
//  Parses a received CSV line and updates target angles
//  Input example: "090,110,110,090,090,090"
// ══════════════════════════════════════════════════════════════════════════════

void parse_command(char* buf) {
  int parsed[NUM_JOINTS];  // Temporary storage for the 6 angles we'll read
  int count = 0;

  // strtok splits a string at delimiter characters (commas here).
  // First call: pass the string → returns pointer to the first token ("090")
  // Later calls: pass NULL → continues where it left off
  char* token = strtok(buf, ",");

  while (token != NULL && count < NUM_JOINTS) {
    int angle = atoi(token);  // atoi = convert text "090" to integer 90

    // constrain() clamps between min and max — prevents unsafe values
    parsed[count++] = constrain(angle, 0, 180);

    token = strtok(NULL, ",");  // Move to next number
  }

  if (count == NUM_JOINTS) {
    // Got exactly 6 values — update all servo targets
    for (int i = 0; i < NUM_JOINTS; i++) {
      target_angles[i] = parsed[i];
    }
    send_current_angles();  // Acknowledge receipt with current positions
  }
  else {
    // Wrong number of values — tell ROS2 something went wrong
    Serial.println("ERR:bad_count");
  }
}


// ══════════════════════════════════════════════════════════════════════════════
//  FUNCTION: move_step
//  Advance every servo ONE step (STEP_SIZE degrees) closer to its target.
//  Called 50 times per second from loop() to create smooth motion.
// ══════════════════════════════════════════════════════════════════════════════

void move_step() {
  bool any_moved = false;

  for (int i = 0; i < NUM_JOINTS; i++) {
    if (current_angles[i] < target_angles[i]) {
      // Too low — step up, but don't go past the target (min() prevents overshoot)
      current_angles[i] = min(current_angles[i] + STEP_SIZE, target_angles[i]);
      any_moved = true;
    }
    else if (current_angles[i] > target_angles[i]) {
      // Too high — step down, don't undershoot (max() prevents undershoot)
      current_angles[i] = max(current_angles[i] - STEP_SIZE, target_angles[i]);
      any_moved = true;
    }
    // If current == target, this servo is already there — nothing to do

    // Write the updated position to the physical servo
    servos[i].write(current_angles[i]);
  }

  // While servos are still moving, send live position feedback back to ROS2.
  // This is optional but lets ros2_to_arduino_bridge.py know the real servo positions.
  if (any_moved) {
    send_current_angles();
  }
}


// ══════════════════════════════════════════════════════════════════════════════
//  FUNCTION: send_current_angles
//  Sends current servo positions to the laptop in CSV format.
//  Output example: "090,110,110,090,090,090\n"
// ══════════════════════════════════════════════════════════════════════════════

void send_current_angles() {
  for (int i = 0; i < NUM_JOINTS; i++) {
    if (i > 0) Serial.print(",");   // Comma separator between values

    // Zero-pad to 3 digits for consistent message length:
    // 9 → "009",  45 → "045",  180 → "180"
    if (current_angles[i] < 100) Serial.print("0");
    if (current_angles[i] < 10)  Serial.print("0");
    Serial.print(current_angles[i]);
  }
  Serial.print("\n");   // Newline marks the end of the message
}

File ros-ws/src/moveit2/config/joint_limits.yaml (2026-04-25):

# joint_limits.yaml allows the dynamics properties specified in the URDF to be overwritten or augmented as needed

# For beginners, we downscale velocity and acceleration limits.
# You can always specify higher scaling factors (<= 1.0) in your motion requests.  # Increase the values below to 1.0 to always move at maximum speed.
default_velocity_scaling_factor: 0.1
default_acceleration_scaling_factor: 0.1

# Specific joint properties can be changed with the keys [max_position, min_position, max_velocity, max_acceleration]
# Joint limits can be turned off with [has_velocity_limits, has_acceleration_limits]
joint_limits:
  jend:
    has_velocity_limits: true
    max_velocity: 1.57 # rad/s (approx 90 deg/s)
    has_acceleration_limits: true
    max_acceleration: 1.0 # rad/s^2
  jhorn:
    has_velocity_limits: true
    max_velocity: 1.57
    has_acceleration_limits: true
    max_acceleration: 1.0
  jlink1:
    has_velocity_limits: true
    max_velocity: 1.57
    has_acceleration_limits: true
    max_acceleration: 1.0
  jlink2:
    has_velocity_limits: true
    max_velocity: 1.57
    has_acceleration_limits: true
    max_acceleration: 1.0
  jrotate1:
    has_velocity_limits: true
    max_velocity: 1.57
    has_acceleration_limits: true
    max_acceleration: 1.0
  jrotate2:
    has_velocity_limits: true
    max_velocity: 1.57
    has_acceleration_limits: true
    max_acceleration: 1.0
  jsgear:
    has_velocity_limits: true
    max_velocity: 1.57
    has_acceleration_limits: true
    max_acceleration: 1.0

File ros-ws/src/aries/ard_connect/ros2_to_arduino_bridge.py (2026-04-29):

#!/usr/bin/env python3
"""
╔══════════════════════════════════════════════════════════════════════════════╗
║                           ros2_to_arduino_bridge.py                                  ║
╠══════════════════════════════════════════════════════════════════════════════╣
║  WHAT THIS FILE DOES:                                                        ║
║    This is the "translator" between ROS2/MoveIt2 and your Arduino UNO.       ║
║    MoveIt2 thinks in joint names and radians (like -1.57 rad for 90°).       ║
║    Arduino controls servos using degrees (0° to 180°).                       ║
║    This script does the conversion and sends commands over USB cable.        ║
║                                                                              ║
║  DATA FLOW (how information travels):                                        ║
║    MoveIt2 plans a path                                                      ║
║      → JointTrajectoryController executes it step by step                    ║
║        → FakeSystem publishes positions on /joint_states 100x per second     ║
║          → THIS FILE reads /joint_states                                     ║
║            → converts radians to servo degrees                               ║
║              → sends "090,110,110,090,090,090\n" over USB                    ║
║                → Arduino moves the physical servos smoothly                  ║
║                                                                              ║
║  HOW TO RUN:                                                                 ║
║    This file is launched automatically by demo.launch.py after 8 seconds.    ║
║    You don't need to run it manually.                                        ║
║                                                                              ║
║  FINDING YOUR ARDUINO PORT:                                                  ║
║    Plug in Arduino, then run:  ls /dev/tty* | grep -E 'USB|ACM'              ║
║    Update serial_port in demo.launch.py to match (usually /dev/ttyACM0).     ║
╚══════════════════════════════════════════════════════════════════════════════╝
"""

# ── IMPORTS ────────────────────────────────────────────────────────────────────
# Think of imports like "loading tools you need before starting work"

import rclpy                        # The main ROS2 Python library
from rclpy.node import Node         # Base class for all ROS2 programs
from sensor_msgs.msg import JointState  # Message type carrying joint positions

import serial                        # PySerial: talks to Arduino over USB
import serial.tools.list_ports       # Lists available USB ports (for debugging)
import math                          # For math.degrees() to convert radians→degrees
import time                          # For time.sleep() to wait on startup
import threading                     # Lets us read Arduino in background


# ══════════════════════════════════════════════════════════════════════════════
#  SECTION 1: JOINT CONFIGURATION TABLE
#  ─────────────────────────────────────
#  This is the most important section to understand.
#  When you get a new servo or change hardware, you edit this table.
# ══════════════════════════════════════════════════════════════════════════════

# JOINT_MAP: tells the bridge how to handle each joint
#
# Format:  'joint_name': (serial_index, zero_angle, direction, limit_low, limit_high)
#
# serial_index  — which slot (0 to 5) in the CSV string goes to which servo
#                 Index 0 = first number in "090,110,110,090,090,090"
#                 Index 5 = last number
#
# zero_angle    — the servo DEGREE when ROS2 joint position = 0.0 radians
#                 Most joints: 90° (servo center = robot zero position)
#                 jlink1, jlink2: 110° (these servos were physically installed
#                 at 110° to match the URDF's zero pose)
#
# direction     — +1 means "positive radian = higher degree"
#                 -1 means "positive radian = lower degree" (reversed servo)
#                 If the real robot moves the WRONG WAY compared to RViz,
#                 change +1 to -1 (or vice versa) for that joint.
#
# limit_low/high — joint limits in radians, matching your URDF file
#                  The script clamps values to stay inside these limits
#
# ⚠ IMPORTANT — SHARED PIN (jsgear and jhorn):
#   Both connector end effectors use the SAME Arduino pin 11.
#   You only ever attach ONE end effector at a time (gripper OR magnet).
#   So both joints are given serial_index = 5, and whichever one ROS2
#   commands simply overwrites position 5 in the CSV string.

JOINT_MAP = {
    # Joint Name    (idx, zero°, dir,  low_rad, high_rad)
    # ─────────────────────────────────────────────────────────────────
    # MG996R motor — rotates the whole arm base left/right
    'jrotate1':  (  0,   90,  +1,   -1.57,   1.57  ),

    # MG996R motor — lifts/lowers the first arm segment
    # zero=110 because this servo was physically set to 110° at the URDF zero pose
    'jlink1':    (  1,  110,  +1,   -1.222,  1.92  ),

    # MG996R motor — lifts/lowers the second arm segment
    # same physical situation as jlink1
    'jlink2':    (  2,  110,  +1,   -1.222,  1.92  ),

    # MG90S motor — wrist rotation (jrotate2 is back as a controllable revolute joint)
    'jrotate2':  (  3,   90,  +1,   -1.2,    1.2   ),

    # MG90S motor — tilts the end (up/down at wrist)
    'jend':      (  4,   90,  +1,   -1.57,   1.57  ),

    # SG90 motor — CONNECTOR 1 (gripper gear).
    # Shares Arduino pin 11 with jhorn below.
    # When the GRIPPER end effector is attached, this controls it.
    'jsgear':    (  5,   90,  +1,   -1.3,    0.0   ),

    # SG90 motor — CONNECTOR 2 (magnet horn).
    # Shares Arduino pin 11 with jsgear above.
    # When the MAGNET end effector is attached, this controls it.
    # Both use index 5 — last command sent to the Arduino wins.
    'jhorn':     (  5,   90,  +1,   -1.3,    0.0   ),
}

# How many values we send per message. Must match Arduino's #define NUM_JOINTS
NUM_JOINTS = 6

# How much a joint must move before we bother sending an update.
# Without this, we'd flood the Arduino with 100 identical messages per second.
# 0.01 radians ≈ 0.57 degrees — small enough to be smooth, large enough to filter noise.
CHANGE_THRESHOLD = 0.01  # radians


# ══════════════════════════════════════════════════════════════════════════════
#  SECTION 2: CONVERSION FUNCTION
#  ────────────────────────────────
#  Pure math: converts radians (ROS2) to degrees (servo hardware)
# ══════════════════════════════════════════════════════════════════════════════
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

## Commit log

2026-04-25 First full Upload
    [ARIES.kicad_pcb, ARIES.kicad_sch, Microservo horn.SLDPRT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]
2026-04-29 Refined Upload
    [full.ros2_control.xacro]
